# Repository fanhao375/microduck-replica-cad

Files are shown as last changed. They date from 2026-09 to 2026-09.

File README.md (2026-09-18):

# Microduck 复刻 · SolidWorks 三维图纸与装配说明书

> **可编辑的 SolidWorks 源文件**（不是 STL），外加一份 21 页的装配安装说明书。**两个版本**：
> **v2.0 飞特 HD-1910 版**（2026-09-12，已装出实物）和 **v1.1 原版 XL330 版**（2026-09-15，踝 / 小腿 / 脚同步改了）。
> 配套主仓：[**fanhao375/microduck-replica**](https://github.com/fanhao375/microduck-replica) —— 整机复刻、电路板与逆向分析都在那边。

> 📦 **压缩包在 [Releases 页](../../releases)（页面右边栏），不在上面的文件列表里。** 374 MB 的 SolidWorks 不适合塞进 git。
> 🖨️ **只想打印、不想看图** → [拓竹 MakerWorld · microduck 飞特版](https://makerworld.com.cn/zh/models/2963569-microduck#profileId-3478428)，一键切片（机械行者Robo 上传，就是这套飞特版）。

<div align="center">
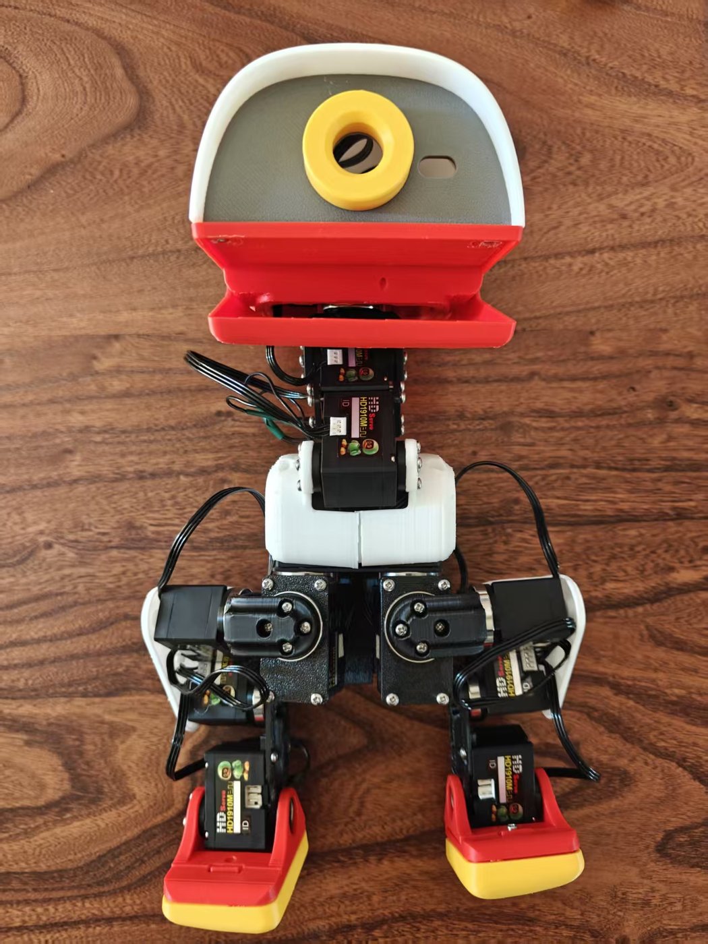
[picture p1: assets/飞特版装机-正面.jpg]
飞特 HD-1910 版装机实物
  
  <br><sub>2026-09-13 · 飞特 HD-1910 版装出来了，15 颗全在位</sub>
</div>

<div align="center">
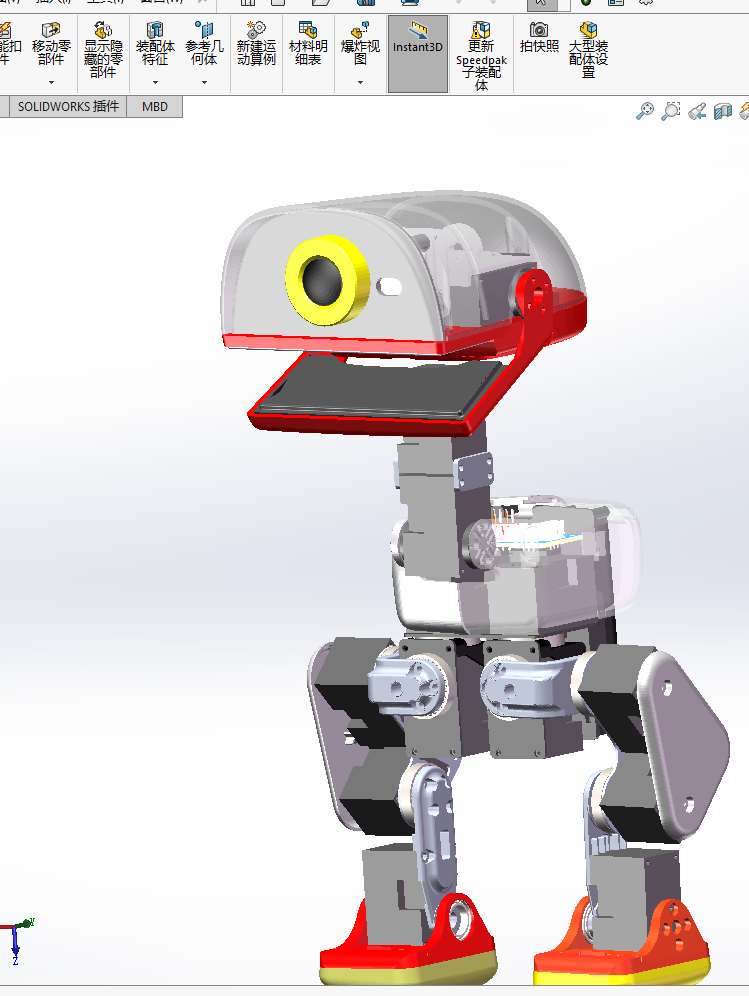
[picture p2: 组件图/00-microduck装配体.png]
microduck 装配体
  
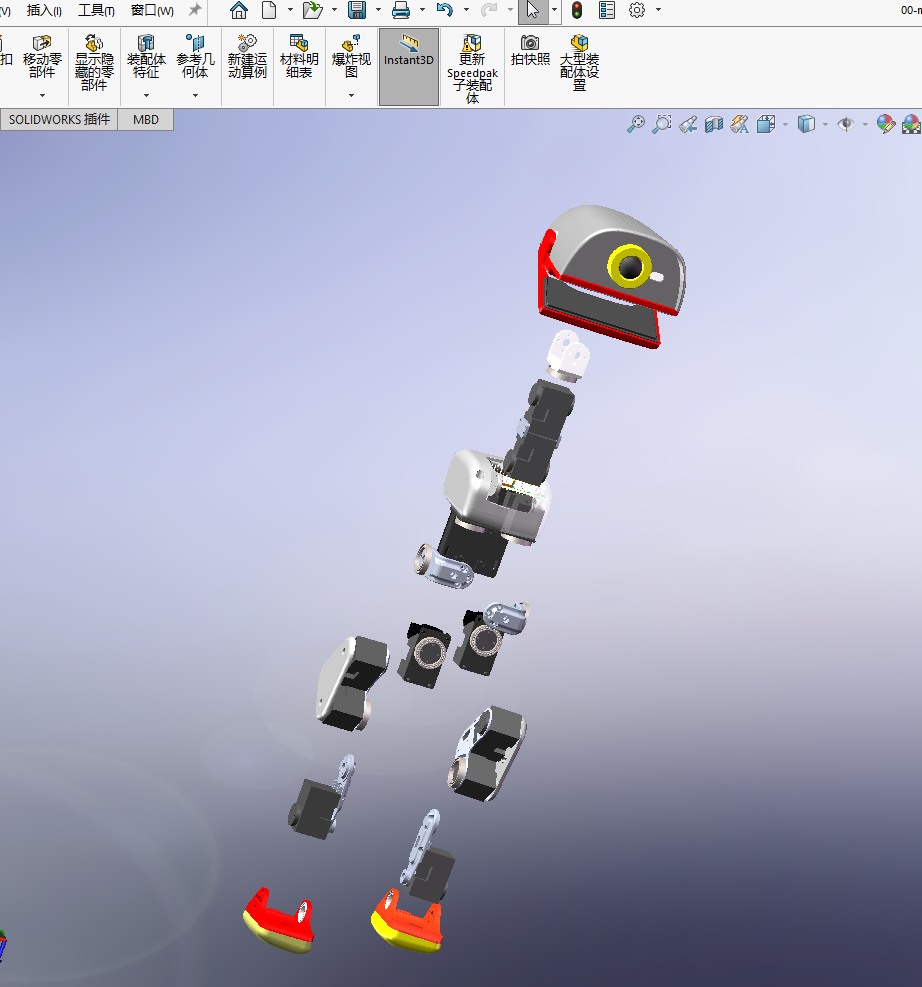
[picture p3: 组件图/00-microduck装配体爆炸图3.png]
microduck 爆炸图
  
</div>

---

## 两个版本，选一个下

| | 原版 · XL330 · **v1.1** | 飞特 · HD-1910 · **v2.0** |
|---|---|---|
| **舵机** | Dynamixel XL330-M288 | 飞特 HD-1910-C001 |
| **文件** | 57 个 SolidWorks，无后缀 | 62 个 SolidWorks + 9 个 STEP，`-FT` 后缀 |
| **差别** | — | **舵盘凸出**，8 个配合件改了（[改了什么](#飞特-hd-1910-版改了什么)） |
| **打印** | 主仓 [`print/`](https://github.com/fanhao375/microduck-replica/tree/master/print) 上游 STL | [`打印/` 3mf](打印/) · [拓竹一键打印](https://makerworld.com.cn/zh/models/2963569-microduck#profileId-3478428) |
| **实物** | — | 已装出（上图） |
| **下载** | [`SolidWorks-XL330-v1.1.zip`](https://github.com/fanhao375/microduck-replica-cad/releases/download/v1.1/SolidWorks-XL330-v1.1.zip) 333 MB | [`SolidWorks-FT.zip`](https://github.com/fanhao375/microduck-replica-cad/releases/download/v2.0/SolidWorks-FT.zip) 373 MB |

两版的踝 / 小腿 / 脚在 2026-09-15 同步成了一套设计；装配说明书和组件图两版通用。

---

## 图纸作者：机械行者Robo

**这套三维图纸和安装说明书，全部由「机械行者Robo」建模、整理、编写。**

他还在做装配视频，有装配上的问题去他那儿留言最快：

<table>
<tr>
<td align="center" width="50%">
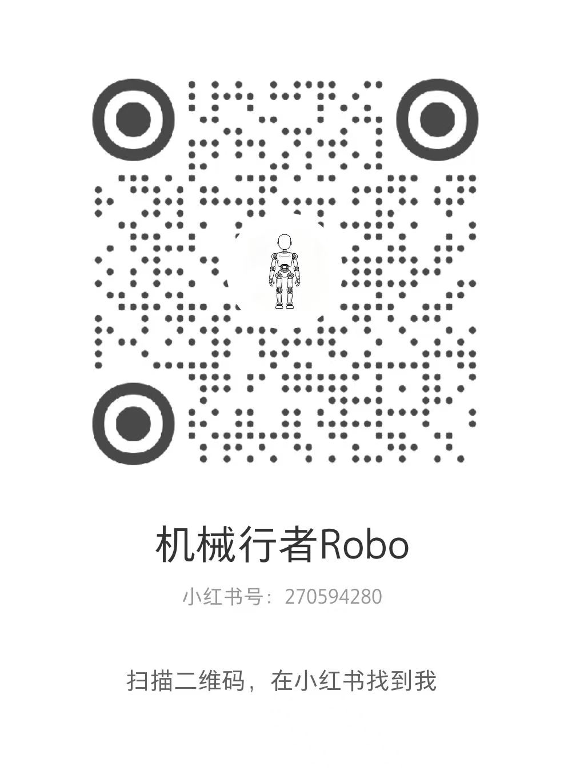
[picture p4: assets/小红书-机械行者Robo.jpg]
小红书 机械行者Robo
  <br>
  <b>小红书 · 机械行者Robo</b><br>
  <sub>小红书号 270594280</sub>
</td>
<td align="center" width="50%">
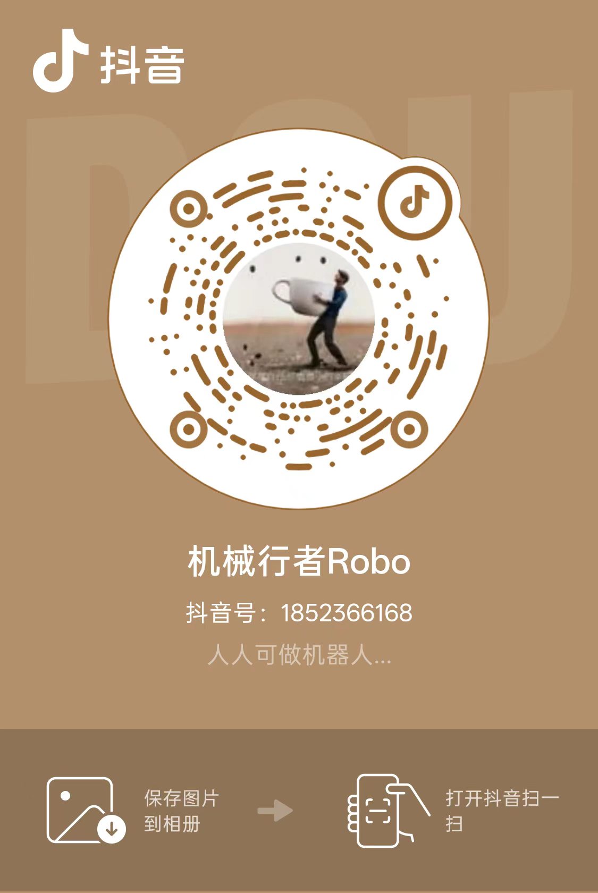
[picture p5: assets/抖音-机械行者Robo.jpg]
抖音 机械行者Robo
  <br>
  <b>抖音 · 机械行者Robo</b><br>
  <sub>抖音号 1852366168 —— 「人人可做机器人」</sub>
</td>
</tr>
</table>

> 觉得图纸有用的话，去关注一下他 —— 这套东西建模和整理的工作量不小，而且是免费放出来的。

---

## 下载

| 要什么 | 在哪 |
|---|---|
| **飞特 HD-1910 版源文件**（v2.0 · 62 个 SolidWorks + 9 个 STEP，解压 435 MB） | 👉 [**下载 `SolidWorks-FT.zip`**](https://github.com/fanhao375/microduck-replica-cad/releases/download/v2.0/SolidWorks-FT.zip) |
| **只要改动件的 STEP**（v2.0 · 9 个，15 MB） | 👉 [**下载 `STEP-changed-parts-FT.zip`**](https://github.com/fanhao375/microduck-replica-cad/releases/download/v2.0/STEP-changed-parts-FT.zip) —— 不用 SolidWorks 也能开 |
| **原版 XL330 版源文件**（v1.1 · 57 个 SolidWorks，解压 348 MB） | 👉 [**下载 `SolidWorks-XL330-v1.1.zip`**](https://github.com/fanhao375/microduck-replica-cad/releases/download/v1.1/SolidWorks-XL330-v1.1.zip)（[v1.0 旧版](../../releases/tag/v1.0) 仍可下） |
| **装配 BOM**（机械行者Robo 整理，35 个打印件 + 16 个外购件，含材料、数量，**2026-09-16 起带轴承和螺丝的采购链接**） | [`BOM/装配BOM-机械行者Robo-2026-09-16-带采购链接.xlsx`](BOM/装配BOM-机械行者Robo-2026-09-16-带采购链接.xlsx)，下面有校对过的表 |
| **装配安装说明书**（21 页 PDF） | [`安装说明书/microduck装配安装说明书.pdf`](安装说明书/microduck装配安装说明书.pdf) |
| **组件图 / 爆炸图**（23 张） | [`组件图/`](组件图/) |
| 🖨️ **打印工程文件**（Bambu Studio `.3mf`，4.9 MB，2026-09-15 版） | [`打印/microduck-飞特版-BambuStudio.3mf`](打印/microduck-飞特版-BambuStudio.3mf) —— **就在仓库里，直接下**。5 个盘、52 个件、P2S / PLA / 0.2 层高，跟拓竹上那个是同一份 |
| 🖨️ **拓竹一键打印** | [MakerWorld · microduck 飞特版](https://makerworld.com.cn/zh/models/2963569-microduck#profileId-3478428) —— 有拓竹打印机的直接云切片 |

> **为什么源文件放 Releases 不放 git**：SolidWorks 是二进制格式，git 存它既不能 diff 也不能合并，
> 只会一版版往历史里堆 —— 改三次图仓库就上 1 GB，而且**历史删不掉**。
> 放 Release 附件则不计入仓库体积，更新时发新版即可，clone 这个仓库始终只有几 MB。

---

## 飞特 HD-1910 版改了什么

原版用 Dynamixel XL330，本仓库主仓走飞特 HD-1910（更便宜、力矩大 2.5 倍、电压额定匹配 —— 见[主仓执行器选型](https://github.com/fanhao375/microduck-replica/blob/master/docs/执行器选型.md)）。
**两款舵机外形接近但舵盘不一样：HD-1910 的舵盘是凸出来的，XL330 是凹进去的。** 所有跟舵盘配合的件都得改：

| 改动件 | 为什么 |
|---|---|
| `left_upper_leg` / `right_upper_leg` 左右上腿 | 髋 pitch 和膝的舵盘位 |
| `leg` 小腿 | 膝和踝的舵盘位 |
| `trunk_base` 躯干底座 | 髋 yaw 舵机安装位 |
| `yaw2roll` 偏航转横滚 | 髋 yaw 舵盘 → 髋 roll 舵机 |
| `bearing_roll` 轴承滚轮 | 髋 roll 轴承座 |
| `01-upper_leg_rigidity_plate` 上腿加固板 | 跟上腿一起改 |
| `99-yaw_roll_motion` 偏航横滚运动 | 头部 yaw/roll，`-F` 和 `-FT` 两个变体 |

**文件命名**：所有件带 `-FT` 后缀（FT = 飞特）。没改的件也带 `-FT`，是为了整套装配体引用一致 —— 27 个件跟 v1.0 内容一样，只是改了名。

**多出来的**：`HD-1910-c001-dan / -shuang`（单盘 / 双盘舵机模型）、`舵机比较.SLDASM`（两款舵机并排对比）、`飞特电机资料1/`（飞特给的 STEP / DWG / 规格图）。

⚠️ 装配说明书 PDF 和组件图**还是 v1.0 的**，装配顺序和步骤不变，只是舵机换了。

---

## XL330 原版 v1.1 改了什么（2026-09-15）

飞特版改踝、小腿、脚那一片时顺手把原版也改了，两版这一区域现在是同一套设计：

```
改了   05_左小腿 · 06_左踝脚 · 14_右小腿 · 15_右踝脚 · 10_头部总成
       ankle_left 脚踝左 · foot_left 左脚 · leg 腿部
新增   deep groove ball bearings gb（轴承模型）
改名   00-microduck装配体 → 00-microduck装配体 XL330-288舵机版本
       ankle_right_脚踝右 → ankle_right脚踝右
```

46 个件跟 v1.0 一样。

---

## 装配 BOM

[`BOM/装配BOM-机械行者Robo-2026-09-16-带采购链接.xlsx`](BOM/装配BOM-机械行者Robo-2026-09-16-带采购链接.xlsx) 是机械行者Robo 按装配体整理的，2026-09-16 版给轴承和螺丝加了他实际下单的淘宝 / 天猫链接（小白照着买就行）。
表里电子件的型号和数量 2026-09-17 由 fanhao375 按主仓查证过的事实校过一遍（电池 NP-F550、舵机 15、`imu_to_dxl` 1、舵机线 17），下面这张表照它排。只有一处跟表不同：

| 表里 | 这里 | 依据 |
|---|---|---|
| 轮辋 / 轮胎 / 滚轮叶片 | 标为**轮滑变体，走路不用** | 上游 `变体-轮滑/`，只有做轮滑功能才打 |

### 一、3D 打印件（35 项）

| # | 零件 | 文件 | 材料 | 数量 | 备注 |
|---|---|---|---|---|---|
| 1 | 头部上壳 | `top_head_shell` | PLA | 1 | |
| 2 | 头部下壳 | `bottom_head_shell` | PLA | 1 | |
| 3 | 面部零件 | `face_part` | PLA | 1 | |
| 4 | 下巴 | `jaw` | PLA | 1 | |
| 5 | 软下巴 | `jaw_soft` | **TPU** | 1 | 软性件 |
| 6 | 软嘴顶部 | `soft_mouth_top` | **TPU** | 1 | 软性件 |
| 7 | 眼睛 | `noenoeil` | PLA | 1 | |
| 8 | 颈部 | `neck` | PLA | 2 | 可换铝合金增强 |
| 9 | 颈部俯仰 | `neck_pitch` | PLA | 1 | |
| 10 | 躯干底座 | `trunk_base` | PLA | 1 | 可换铝合金增强 |
| 11 | 左壳 | `left_shell` | PLA | 1 | |
| 12 | 右壳 | `right_shell` | PLA | 1 | |
| 13 | 髋部左 | `hip_l` | PLA | 2 | |
| 14 | 偏航转横滚 | `yaw2roll` | PLA | 1 | |
| 15 | 偏航横滚运动 | `yaw_roll_motion` | PLA | 1 | |
| 16 | 腿部 | `leg` | PLA | 2 | |
| 17 | 左上腿 | `left_upper_leg` | PLA | 1 | |
| 18 | 右上腿 | `right_upper_leg` | PLA | 1 | |
| 19 | 上腿加固板 | `upper_leg_rigidity_plate` | PLA | 2 | 可换铝合金增强 |
| 20 | 左脚 | `foot_left` | PLA | 1 | |
| 21 | 右脚 | `foot_right` | PLA | 1 | |
| 22 | 左脚底 | `sole_left` | PLA | 1 | |
| 23 | 右脚底 | `sole_right` | PLA | 1 | |
| 24 | 脚踝左 | `ankle_left` | PLA | 1 | |
| 25 | 脚踝右 | `ankle_right` | PLA | 1 | |
| 26 | 脚踝左 V1 | `ankle_l_v1` | PLA | 1 | 备选，与 24 二选一 |
| 27 | 脚踝右 V1 | `ankle_r_v1` | PLA | 1 | 备选，与 25 二选一 |
| 28 | 轮辋 | `rim` | PLA | 4 | **轮滑变体，走路不用** |
| 29 | 轮胎 | `tire` | TPU | 4 | **轮滑变体，走路不用** |
| 30 | 滚轮叶片 | `roller_blade` | PLA | 2 | **轮滑变体，走路不用** |
| 31 | M12 镜头座 | `m12_lens_holder` | PLA | 1 | |
| 32 | 电机支架 | `motor_support` | PLA | 1 | |
| 33 | 电源支架 | `power_support` | PLA | 1 | |
| 34 | 香蕉形 PCB 锁扣 | `banana_pcb_locker` | PLA | 1 | |
| 35 | 轴承滚轮 | `bearing_roll` | PLA | 2 | 可换铝合金增强 |

### 二、外购件（16 项 + 螺纹胶）

| # | 件 | 数量 | 备注 |
|---|---|---|---|
| 36 | Radxa Zero 3W 主控 | 1 | [主仓电控采购清单](https://github.com/fanhao375/microduck-replica/blob/master/docs/电控采购清单.md) |
| 37 | RPI Robot HAT 电路板 | 1 | 官方开源，嘉立创打样；或[不打 HAT 飞线](https://github.com/fanhao375/microduck-replica/blob/master/docs/不打HAT.md) |
| 38 | imu_to_dxl 电路板 | **1** | 主仓自绘，[hardware/imu_to_dxl](https://github.com/fanhao375/microduck-replica/tree/master/hardware/imu_to_dxl) |
| 39 | 舵机 | **15** | XL330-M288 或飞特 **HD-1910-C001** 二选一；13 单盘 + 2 双盘 |
| 40 | 舵机线缆 | 17 | 舵机自带一根，调试和总线分支要另买；飞特 2.0 mm、Dynamixel 2.5 mm |
| 41 | 电池 | 1 | **NP-F550**，2S |
| 42 | 电池座 | 1 | NP-F 电池仓 + 取电扣板 |
| 43 | IMX219 摄像头 | 1 | |
| 44 | 扬声器 | 1 | 走 HAT 音频才要 |
| 45 | 轴承 10×15×3 | 3 | 机械行者Robo 买的：[淘宝 963037239628](https://item.taobao.com/item.htm?id=963037239628&skuId=6069280211062)（选 10×15×3 那个 SKU） |
| 46 | 轴承 16×22×4 | 11 | 机械行者Robo 买的：[天猫 978199812185](https://detail.tmall.com/item.htm?id=978199812185&skuId=6245616343131) |
| 47 | 轴承 6×12×3 | 2 | 轮滑变体用，走路不用买。同一家：[淘宝 963037239628](https://item.taobao.com/item.htm?id=963037239628&skuId=6068333830994)（选 6×12×3） |
| 48 | 螺丝 M2×5 | 若干 | 机械行者Robo 买的：[天猫 637524754721](https://detail.tmall.com/item.htm?id=637524754721&skuId=5802482233046)；每种多少颗见[主仓紧固件反推](https://github.com/fanhao375/microduck-replica/blob/master/docs/紧固件反推.md) |
| 49 | 螺丝 M2×6 | 若干 | 同一家：[天猫 637524754721](https://detail.tmall.com/item.htm?id=637524754721&skuId=5802482233047) |
| 50 | 螺丝 M2.5×6 | 若干 | 同一家：[天猫 637524754721](https://detail.tmall.com/item.htm?id=637524754721&skuId=61808188996) |
| 51 | 螺纹胶 | 1 | 乐泰 243，原表没列，装配说明书要求 |

---

## 打印

**[`打印/microduck-飞特版-BambuStudio.3mf`](打印/microduck-飞特版-BambuStudio.3mf)** —— 机械行者Robo 排好盘的 Bambu Studio 工程，跟[拓竹 MakerWorld](https://makerworld.com.cn/zh/models/2963569-microduck#profileId-3478428) 上传的是同一份。

| 项 | 值 |
|---|---|
| 打印机 | Bambu Lab **P2S**，0.4 喷嘴 |
| 耗材 | PLA Basic |
| 层高 | 0.2 mm |
| 盘数 | **5 盘**，52 个对象 —— 飞特版全部打印件 |

<table>
<tr>
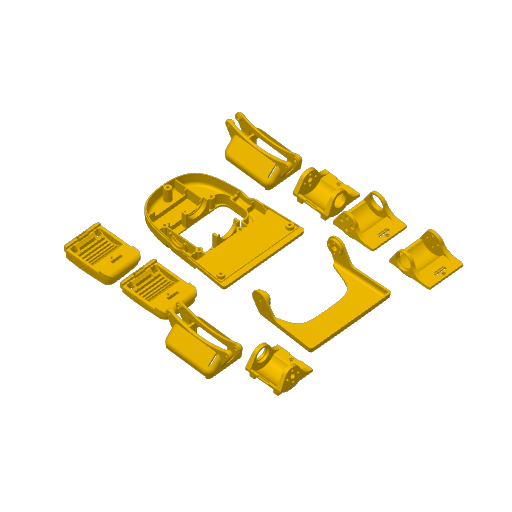
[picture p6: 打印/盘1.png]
<td align="center"><br><sub>盘 1</sub></td>
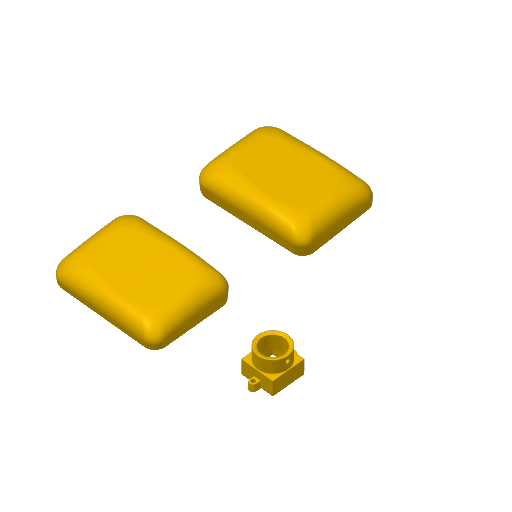
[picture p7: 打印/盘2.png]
<td align="center"><br><sub>盘 2</sub></td>
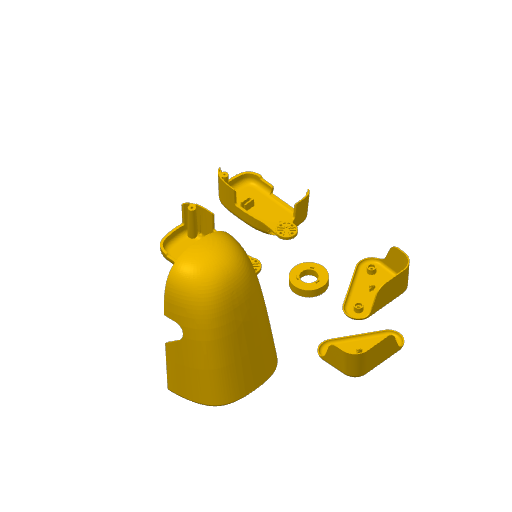
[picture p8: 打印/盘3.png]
<td align="center"><br><sub>盘 3</sub></td>
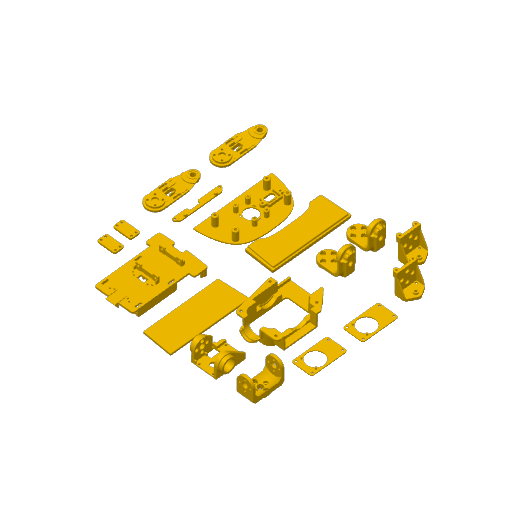
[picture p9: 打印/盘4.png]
<td align="center"><br><sub>盘 4</sub></td>
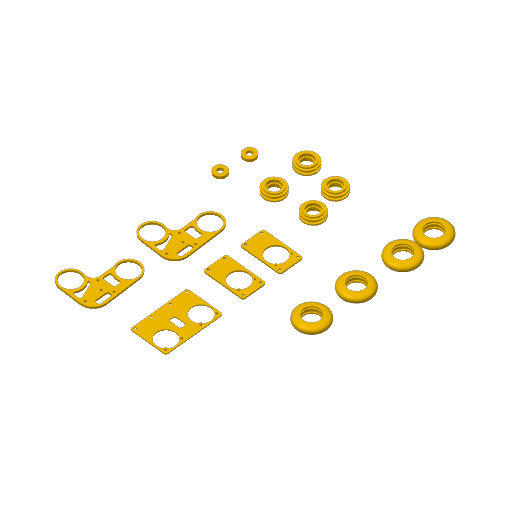
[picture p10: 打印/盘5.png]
<td align="center"><br><sub>盘 5</sub></td>
</tr>
</table>

**怎么用**：Bambu Studio 打开 → 切片 → 打印，五盘依次来。**不是拓竹打印机**也能用：任何切片软件都能导入 `.3mf` 拿到模型和排盘，只是打印参数要按自己的机器重设。

耗材、螺丝、热熔螺母的采购在[主仓机械采购清单](https://github.com/fanhao375/microduck-replica/blob/master/docs/机械采购清单.md)。

---

## 组件清单（15 个）

| 序号 | 组件 | 英文 | 位置 / 功能 |
|---|---|---|---|
| 01 | 躯干主体 | Torso | 机身主体，**全部组件的装配基准件**，承载左/右腿、颈部与控制器 |
| 02 | 左髋 | Left Hip | 左腿根部髋关节（Pitch），腿部前后摆动 |
| 03 | 左髋 Roll | Left Hip Roll | 左腿髋部横滚关节，腿部侧向摆动 |
| 04 | 左大腿 | Left Thigh | 连接髋关节与小腿 |
| 05 | 左小腿 | Left Calf | 连接大腿与踝关节 |
| 06 | 左踝脚 | Left Ankle & Foot | 踝关节及脚部，足部转动与支撑 |
| 07 | 颈根 | Neck Base | 颈部与机身连接处的旋转底座（Yaw） |
| 08 | 颈俯仰 | Neck Pitch | 颈部俯仰摆动关节 |
| 09 | 头 Yaw / Roll | Head Yaw / Roll | 头部水平摆动与横滚关节 |
| 10 | 头部总成 | Head Assembly | 头部完整组件，含外壳、摄像头等 |
| 11 | 右髋 | Right Hip | 与 02 镜像对称 |
| 12 | 右髋 Roll | Right Hip Roll | 与 03 镜像对称 |
| 13 | 右大腿 | Right Thigh | 与 04 镜像对称 |
| 14 | 右小腿 | Right Calf | 与 05 镜像对称 |
| 15 | 右踝脚 | Right Ankle & Foot | 与 06 镜像对称 |

## 装配顺序

**按编号 01 → 15 依次装，就是推荐的整机装配顺序：**

```
1.  01           躯干主体 —— 作为整机基准先行固定
2.  02 → 06      左腿   左髋 → 左髋Roll → 左大腿 → 左小腿 → 左踝脚
3.  07 → 10      颈头   颈根 → 颈俯仰 → 头Yaw/Roll → 头部总成
4.  11 → 15      右腿   右髋 → 右髋Roll → 右大腿 → 右小腿 → 右踝脚
```

**每一步的详细步骤、配图和注意事项，见** [装配安装说明书 PDF](安装说明书/microduck装配安装说明书.pdf)。

---

## 组件图

<table>
<tr>
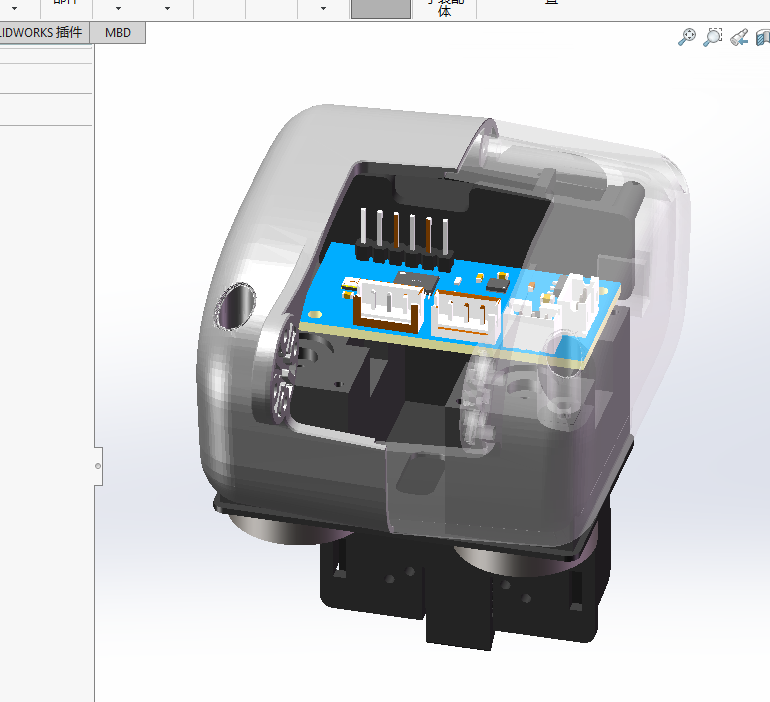
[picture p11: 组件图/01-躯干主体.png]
<td align="center"><br><sub><b>01</b> 躯干主体</sub></td>
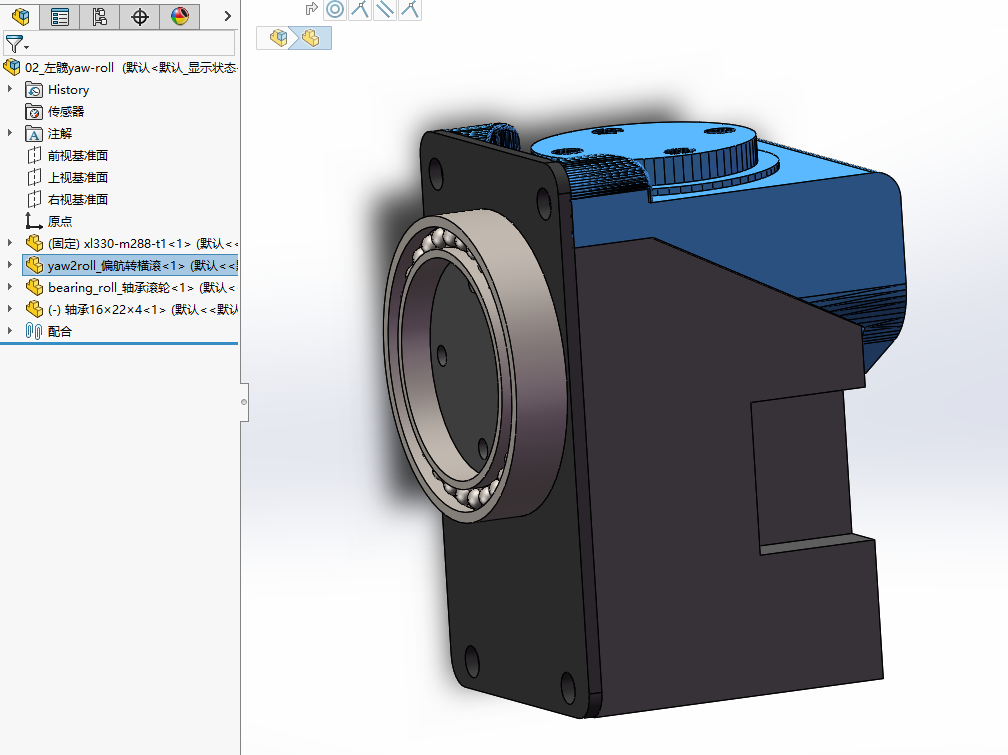
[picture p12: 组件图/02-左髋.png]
<td align="center"><br><sub><b>02</b> 左髋</sub></td>
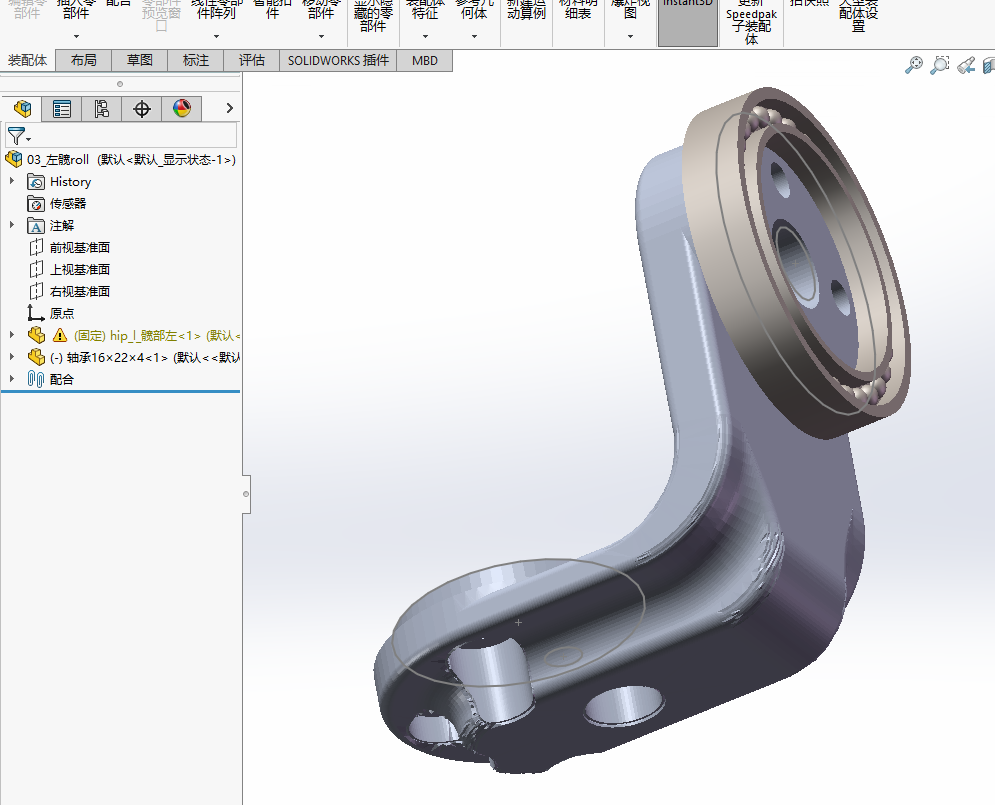
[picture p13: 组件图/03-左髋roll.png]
<td align="center"><br><sub><b>03</b> 左髋 Roll</sub></td>
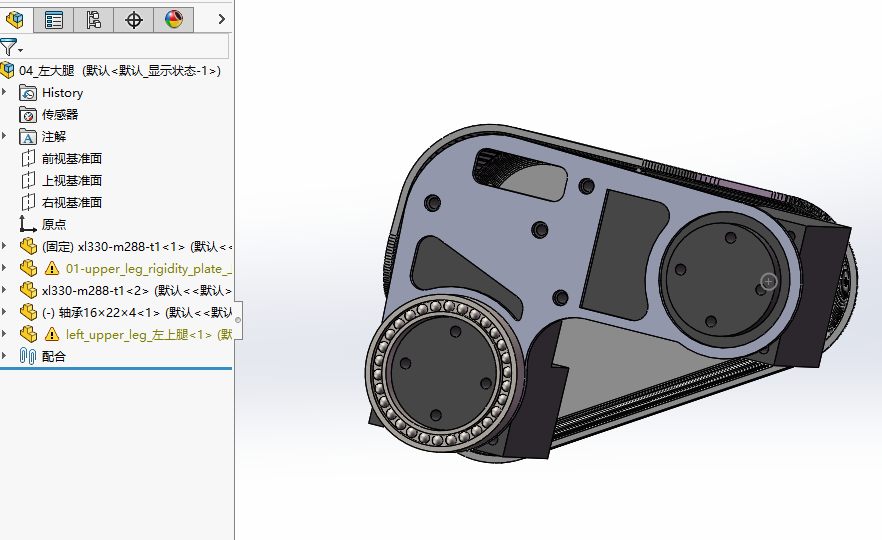
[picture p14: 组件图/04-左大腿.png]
<td align="center"><br><sub><b>04</b> 左大腿</sub></td>
</tr>
<tr>
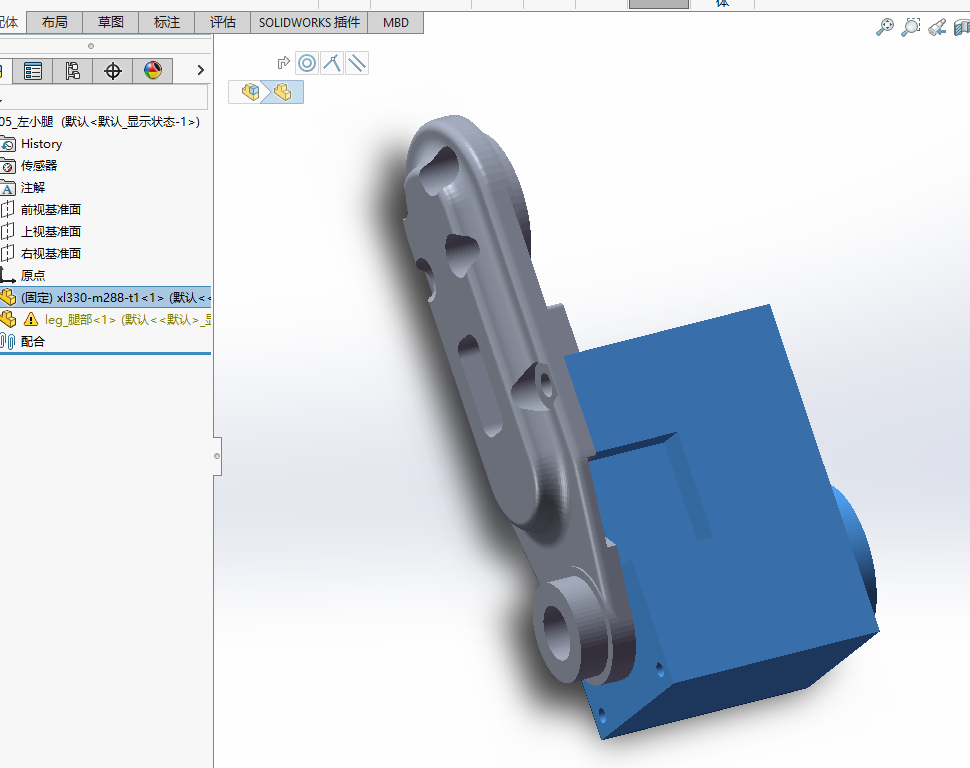
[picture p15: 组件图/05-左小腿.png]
<td align="center"><br><sub><b>05</b> 左小腿</sub></td>
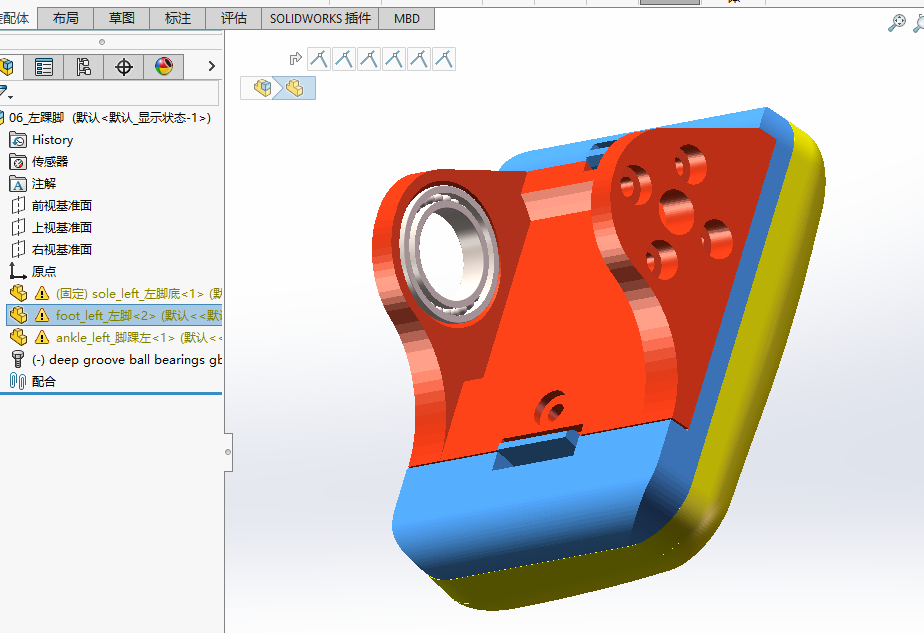
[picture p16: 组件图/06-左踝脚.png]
<td align="center"><br><sub><b>06</b> 左踝脚</sub></td>
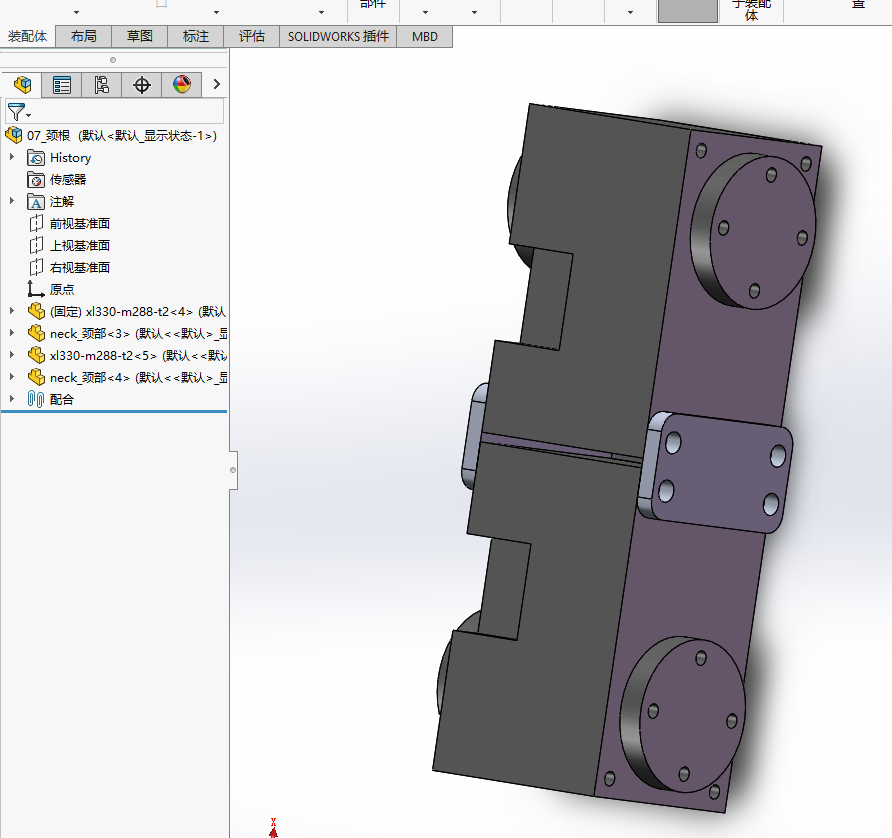
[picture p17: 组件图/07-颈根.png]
<td align="center"><br><sub><b>07</b> 颈根</sub></td>
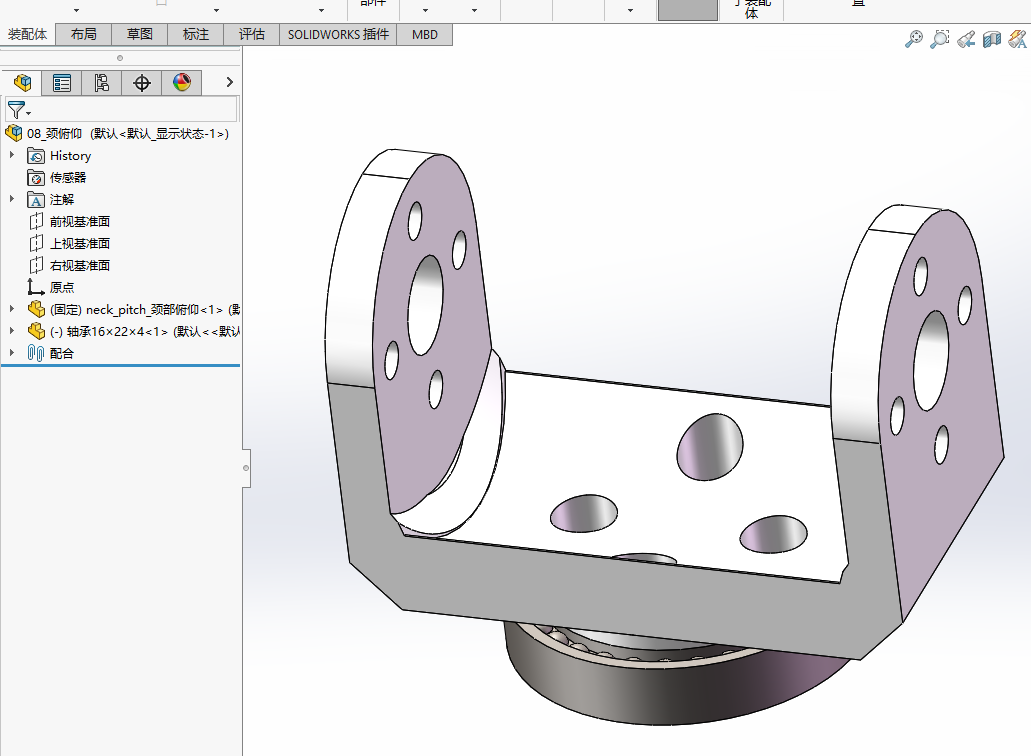
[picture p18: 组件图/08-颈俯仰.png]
<td align="center"><br><sub><b>08</b> 颈俯仰</sub></td>
</tr>
<tr>
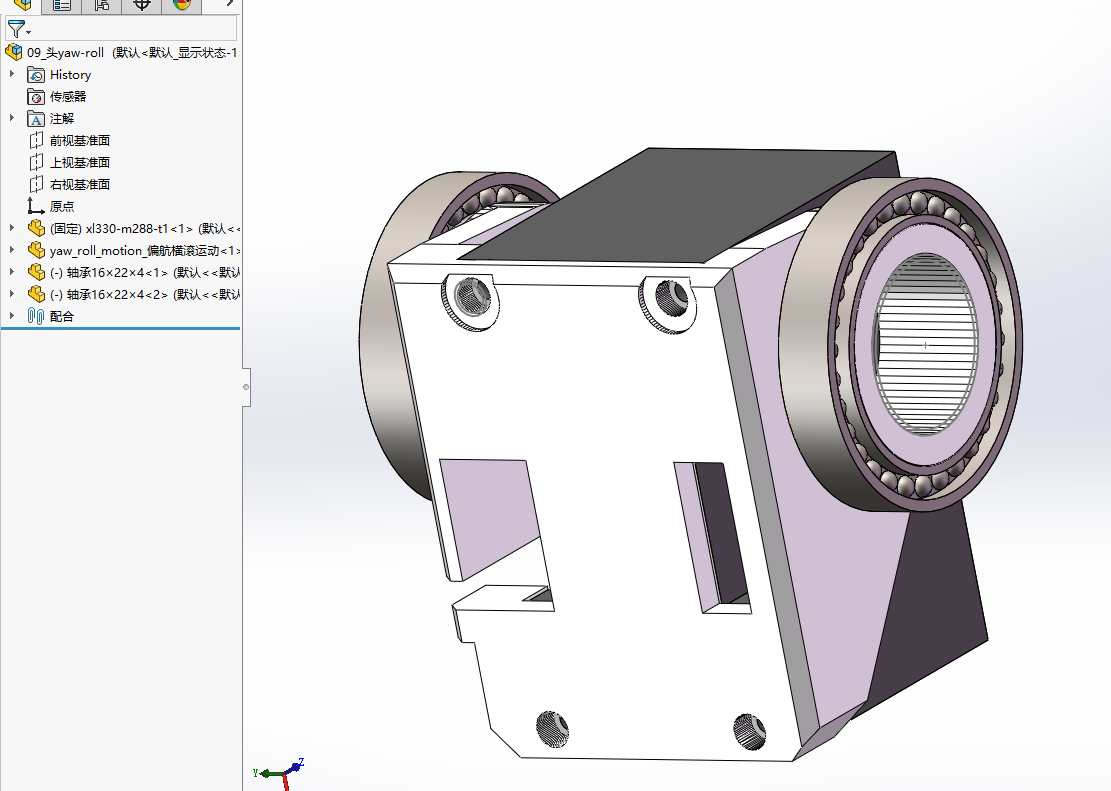
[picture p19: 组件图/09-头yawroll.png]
<td align="center"><br><sub><b>09</b> 头 Yaw/Roll</sub></td>
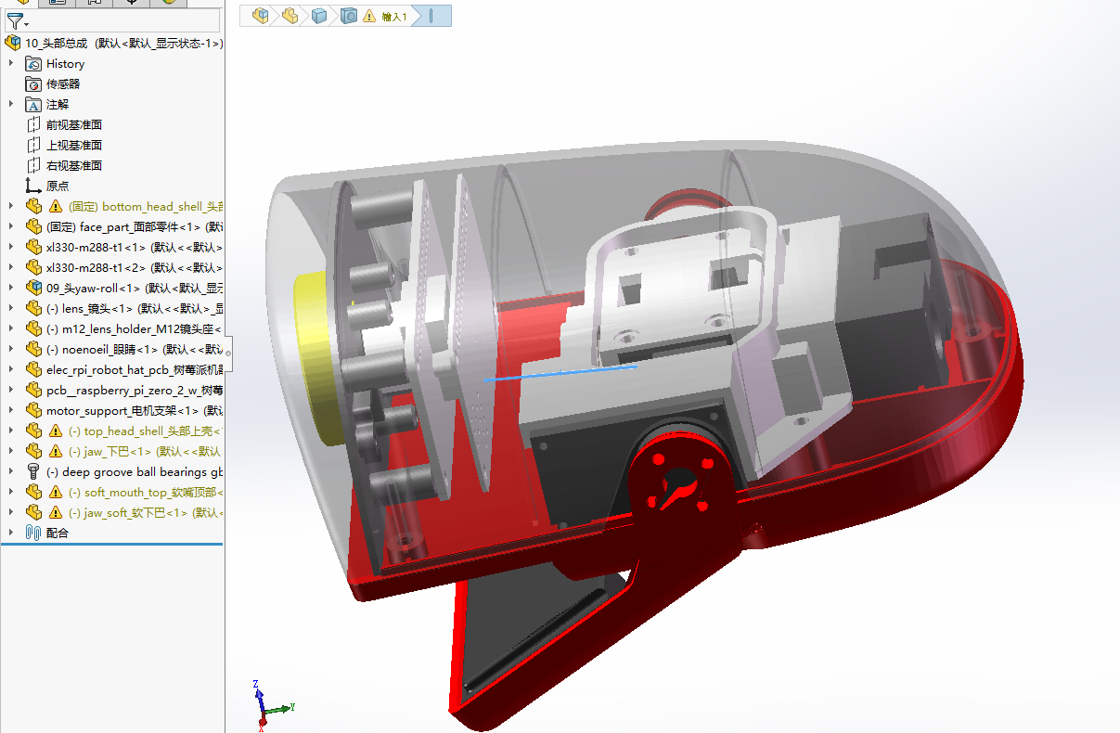
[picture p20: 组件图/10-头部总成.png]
<td align="center"><br><sub><b>10</b> 头部总成</sub></td>
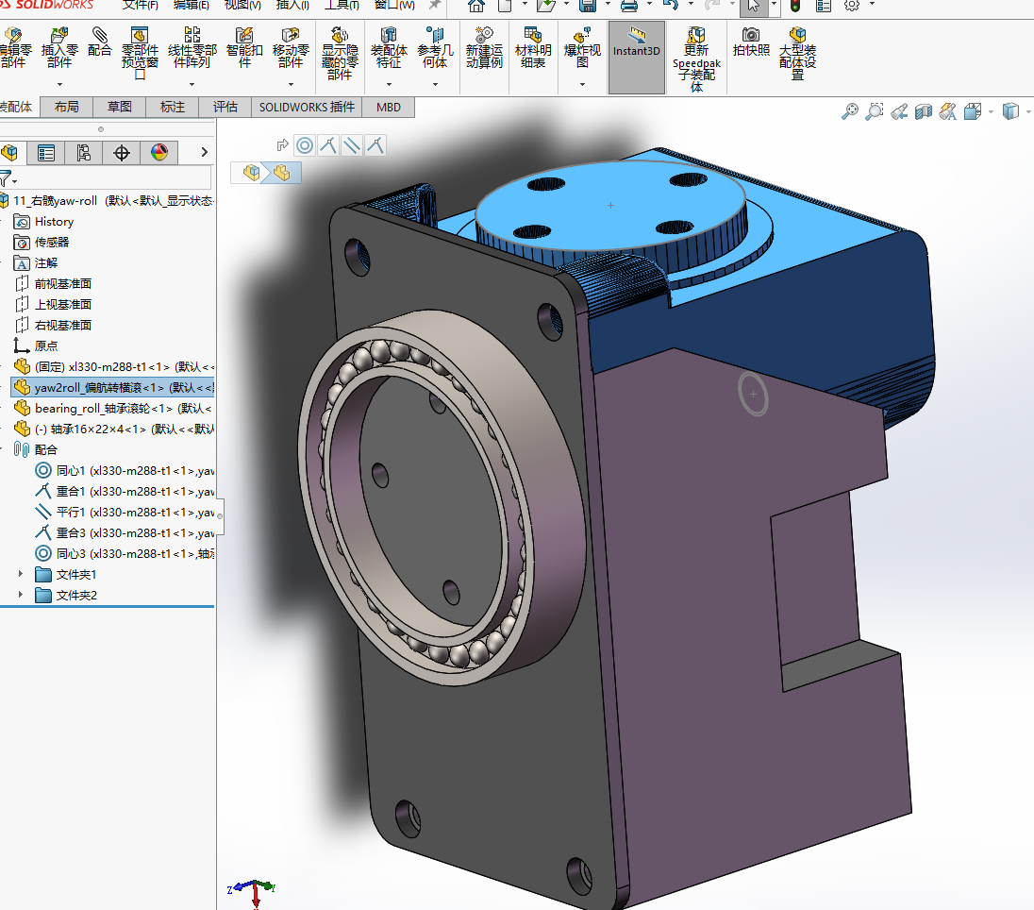
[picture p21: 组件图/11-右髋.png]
<td align="center"><br><sub><b>11</b> 右髋</sub></td>
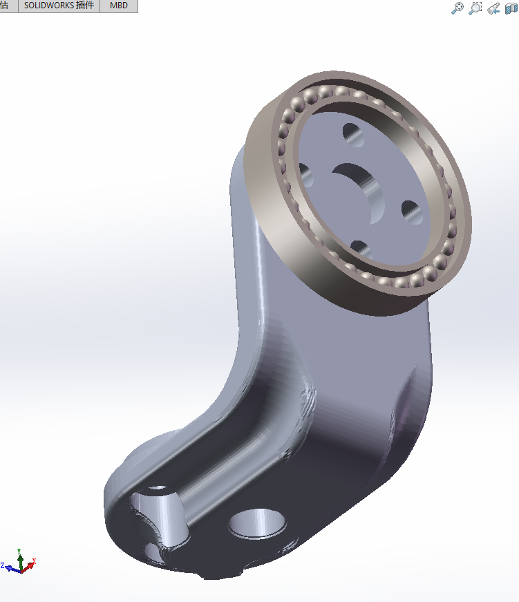
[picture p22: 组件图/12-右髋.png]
<td align="center"><br><sub><b>12</b> 右髋 Roll</sub></td>
</tr>
<tr>
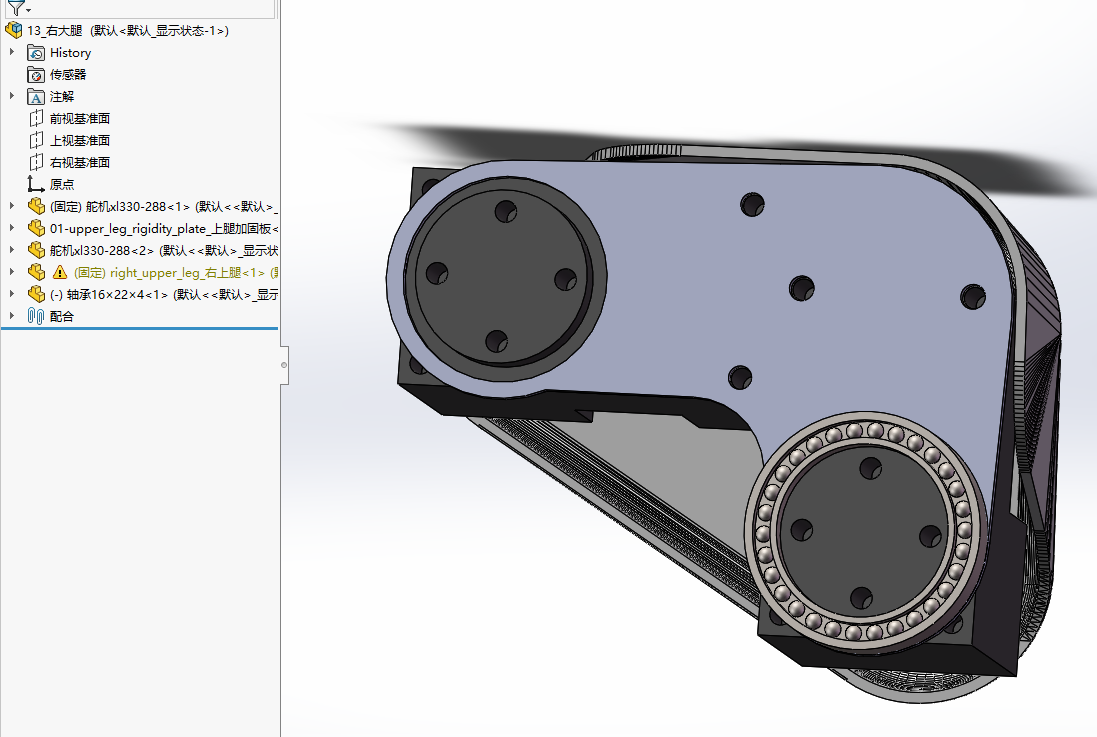
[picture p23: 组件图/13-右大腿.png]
<td align="center"><br><sub><b>13</b> 右大腿</sub></td>
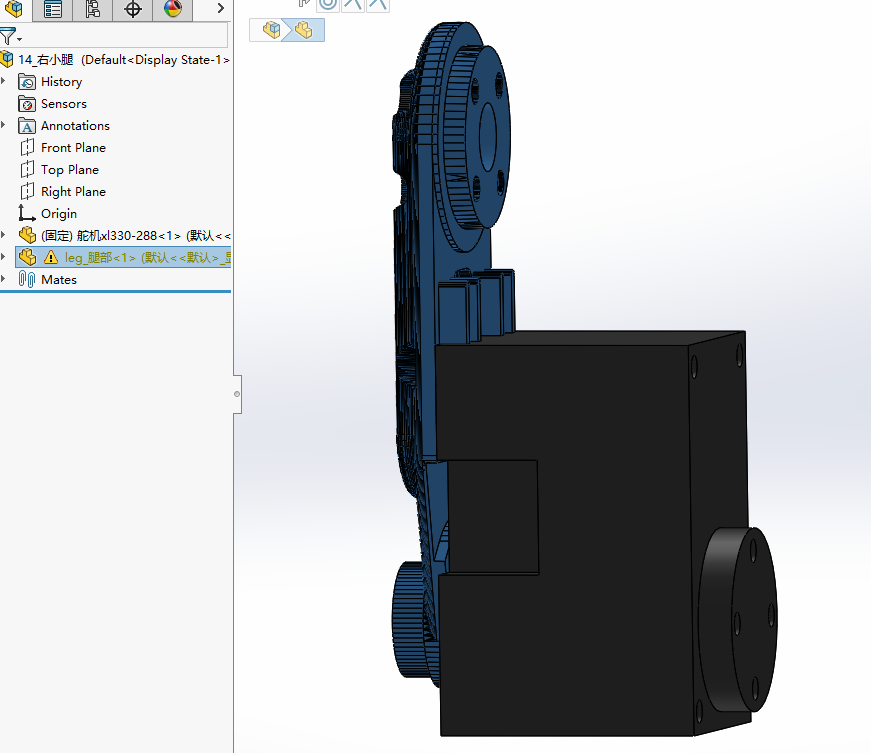
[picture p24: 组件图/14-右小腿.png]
<td align="center"><br><sub><b>14</b> 右小腿</sub></td>
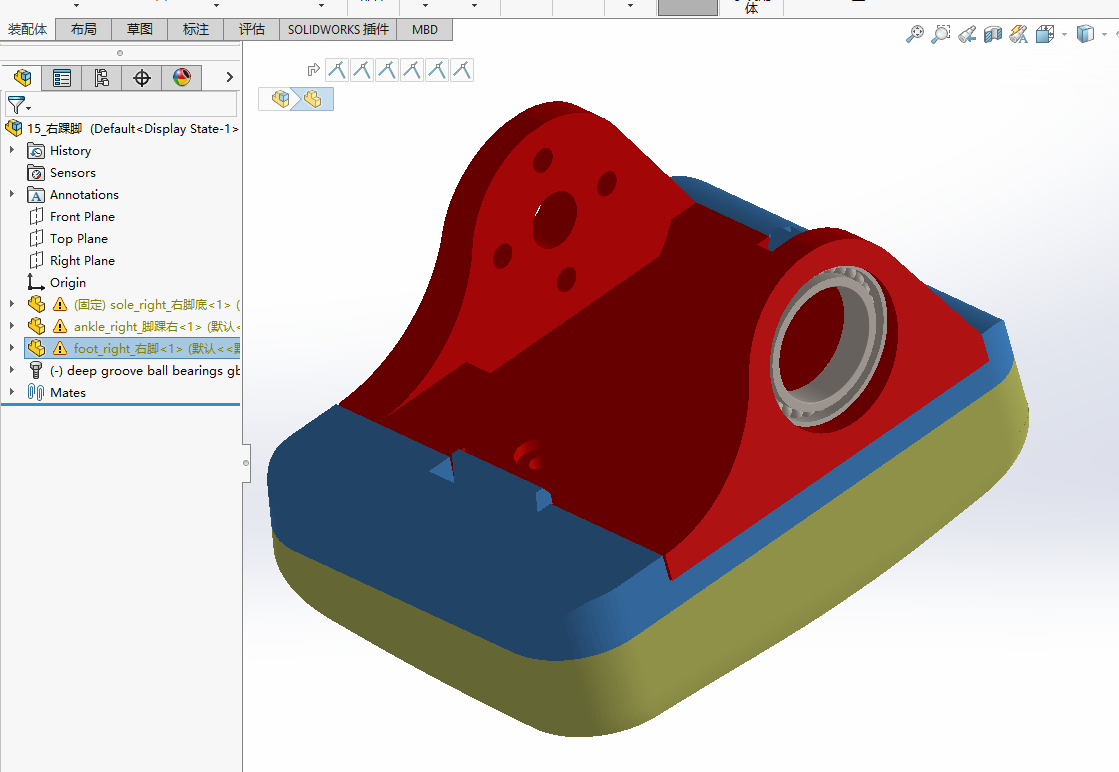
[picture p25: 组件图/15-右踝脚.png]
<td align="center"><br><sub><b>15</b> 右踝脚</sub></td>
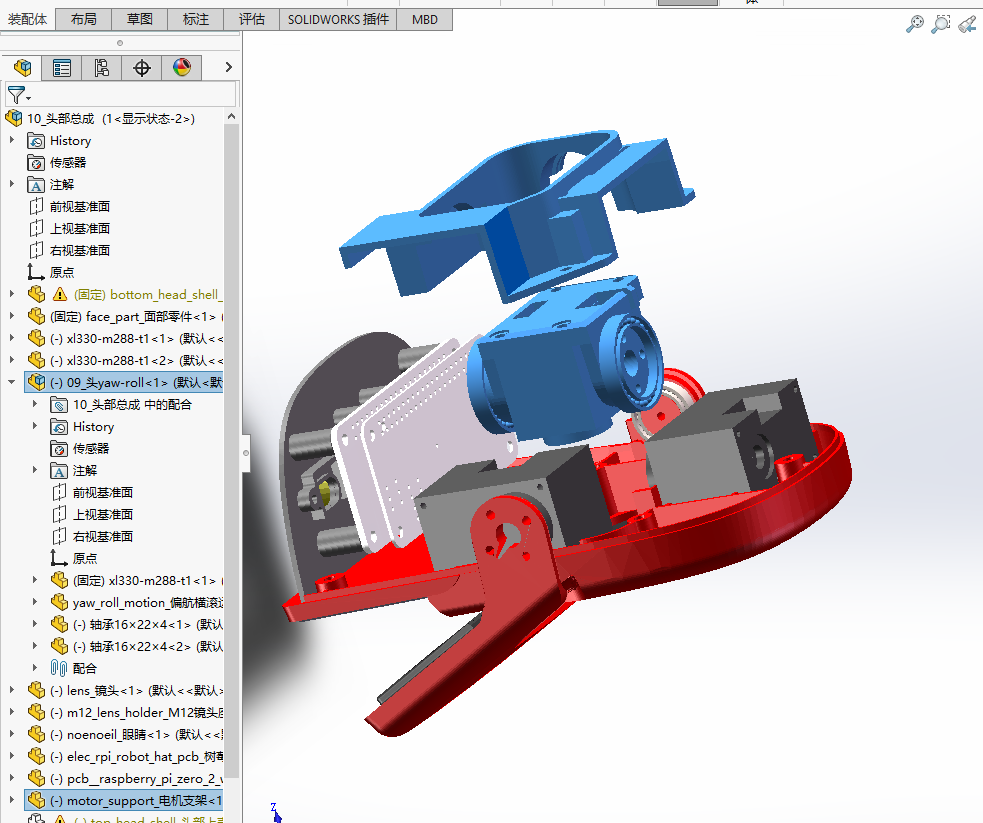
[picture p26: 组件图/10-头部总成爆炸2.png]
<td align="center"><br><sub>头部总成（爆炸）</sub></td>
</tr>
</table>

<div align="center">
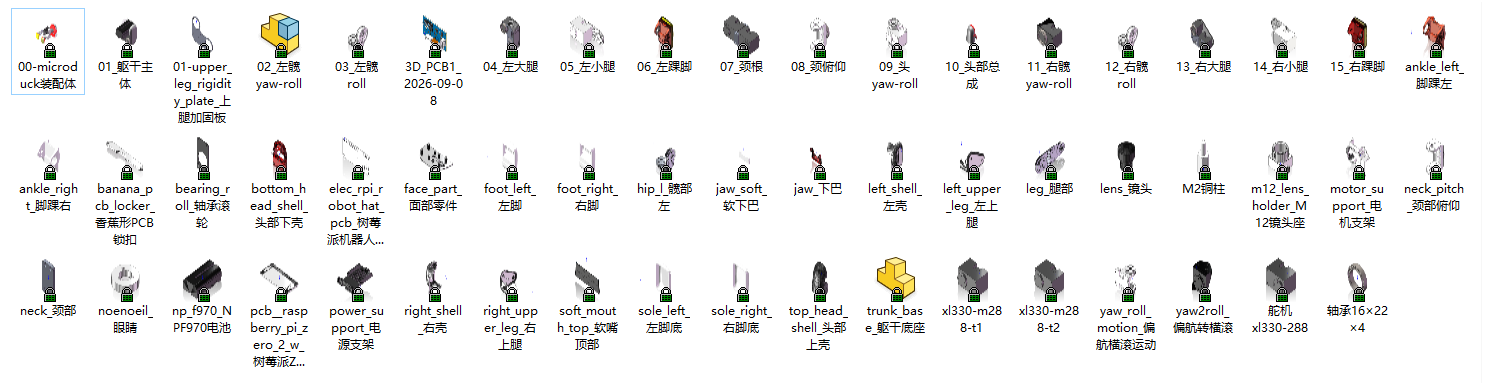
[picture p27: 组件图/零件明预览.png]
零件总览
  <br>
  <sub>全部零件总览</sub>
</div>

---

## 文件清单

### 装配体（16 个 `.SLDASM`）

`00-microduck装配体` 是总装，下面 15 个是分组件：

```
00-microduck装配体      70.3 MB      08_颈俯仰               0.3 MB
01_躯干主体             20.5 MB      09_头yaw-roll          0.7 MB
02_左髋yaw-roll         2.5 MB      10_头部总成             22.2 MB
03_左髋roll             3.8 MB      11_右髋yaw-roll         2.5 MB
04_左大腿               1.9 MB      12_右髋roll             3.8 MB
05_左小腿               1.9 MB      13_右大腿               2.0 MB
06_左踝脚               9.3 MB      14_右小腿               1.8 MB
07_颈根                 0.1 MB      15_右踝脚               9.3 MB
```

### 零件（40 个 `.SLDPRT`）

| 类别 | 零件 |
|---|---|
| **躯干 / 外壳** | `trunk_base_躯干底座` · `left_shell_左壳` · `right_shell_右壳` · `power_support_电源支架` · `banana_pcb_locker_香蕉形PCB锁扣` |
| **腿** | `leg_腿部` · `left_upper_leg_左上腿` · `right_upper_leg_右上腿` · `hip_l_髋部左` · `yaw2roll_偏航转横滚` · `yaw_roll_motion_偏航横滚运动` · `01-upper_leg_rigidity_plate_上腿加固板` |
| **踝 / 脚** | `ankle_left_脚踝左` · `ankle_right_脚踝右` · `foot_left_左脚` · `foot_right_右脚` · `sole_left_左脚底` · `sole_right_右脚底` |
| **颈 / 头** | `neck_颈部` · `neck_pitch_颈部俯仰` · `top_head_shell_头部上壳` · `bottom_head_shell_头部下壳` · `face_part_面部零件` · `jaw_下巴` · `jaw_soft_软下巴` · `soft_mouth_top_软嘴顶部` · `noenoeil_眼睛` |
| **摄像头** | `m12_lens_holder_M12镜头座` · `lens_镜头` |
| **电路板** | `3D_PCB1_2026-09-08`（imu_to_dxl，2026-09-08 版）· `elec_rpi_robot_hat_pcb_树莓派机器人HAT电路板` · `pcb__raspberry_pi_zero_2_w_树莓派Zero2W电路板` |
| **标准件 / 外购** | `舵机xl330-288` · `xl330-m288-t1` · `xl330-m288-t2` · `轴承16×22×4` · `bearing_roll_轴承滚轮` · `M2铜柱` · `motor_support_电机支架` · `np_f970_NPF970电池` |

### 两处命名要留意

- **`np_f970_NPF970电池`** —— 文件名沿用了上游的 `np_f970`，但**实物是 NP-F550**。
  主仓实测上游网格包围盒为 **70.8 × 38.6 × 20.6 mm**，正是 F550/F570 的尺寸；真 NP-F970 厚约 60 mm，
  **买错装不进去，而且 300 g 会吃掉整机预算的三分之一**。详见
  [主仓 BOM 的电池型号勘误](https://github.com/fanhao375/microduck-replica/blob/master/BOM.md)。
- **`pcb__raspberry_pi_zero_2_w`** —— 同样是上游的占位命名，**实机主控是 Radxa Zero 3W**（RK3566），
  只是外形同为 Pi Zero。见[主仓的硬件方案逆向](https://github.com/fanhao375/microduck-replica/blob/master/docs/硬件方案逆向.md)。

---

## 通用注意事项（摘自说明书）

- 装配前对照 BOM 清点零件数量与规格，确认 **M2 / M2.5** 螺丝与紧固件齐全
- **舵机类关节件：装配前先通电归中位再锁紧**，避免行程偏移
- 螺丝**对角分步预紧**，避免单边受力导致零件变形；塑料件切勿过度锁紧
- **左右对称件（髋 / 大腿 / 小腿 / 踝脚）务必区分左右**，切勿装反
- 线缆统一固定、预留关节活动余量，严禁压线、夹线、缠绕
- 每完成一个活动关节，转动测试一次，检查是否干涉、卡滞、异响
- 首次通电前检查所有电气连接、绝缘与极性

**推荐工具**：十字/内六角螺丝刀 · 镊子 · 螺纹胶 · 舵机中位调试工具或控制板。

---

## 声明与许可

> ⚠️ **这是第三方复刻件，不是官方设计。** 与 Pollen Robotics 无隶属关系，未获其背书。

本套图纸依据 [`pollen-robotics/microduck_rl`](https://github.com/pollen-robotics/microduck_rl) 公开发布的
STL 网格重建为可编辑的 SolidWorks 参数模型。上游 3D 模型许可为 **CC BY-NC-SA**，
因此本仓库的图纸作为衍生作品同样以 **[CC BY-NC-SA 4.0](https://creativecommons.org/licenses/by-nc-sa/4.0/deed.zh)** 发布：
**署名 · 非商业性使用 · 相同方式共享**。

- **图纸与说明书著作权归「机械行者Robo」**，转载与二次分发请保留署名
- 文档文字部分同样按 CC BY-NC-SA 4.0 发布
- Microduck 是 Pollen Robotics 的商业产品，本仓库不提供任何官方支持

**发现问题**请开 [issue](../../issues)，或到上面两个账号留言。

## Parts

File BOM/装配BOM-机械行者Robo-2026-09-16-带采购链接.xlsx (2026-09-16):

序号 | 类别 | 名称 | 原文件名 | 材料 | 数量 | 备注
一、3D打印件（需打印）
1 | 3D打印件 | 头部上壳 | top_head_shell_头部上壳.stp | PLA | 1
2 | 3D打印件 | 头部下壳 | bottom_head_shell_头部下壳.stp | PLA | 1
3 | 3D打印件 | 面部零件 | face_part_面部零件.stp | PLA | 1
4 | 3D打印件 | 下巴 | jaw_下巴.stp | PLA | 1
5 | 3D打印件 | 软下巴 | jaw_soft_软下巴.stp | PLA | 1 | 软性件，建议改用TPU软料
6 | 3D打印件 | 软嘴顶部 | soft_mouth_top_软嘴顶部.stp | PLA | 1 | 软性件，建议改用TPU软料
7 | 3D打印件 | 眼睛 | noenoeil_眼睛.stp | PLA | 1
8 | 3D打印件 | 颈部 | neck_颈部.stp | PLA | 2 | 可用铝合金，增加强度
9 | 3D打印件 | 颈部俯仰 | neck_pitch_颈部俯仰.stp | PLA | 1
10 | 3D打印件 | 躯干底座 | trunk_base_躯干底座.stp | PLA | 1 | 可用铝合金，增加强度
11 | 3D打印件 | 左壳 | left_shell_左壳.stp | PLA | 1
12 | 3D打印件 | 右壳 | right_shell_右壳.stp | PLA | 1
13 | 3D打印件 | 髋部左 | hip_l_髋部左.stp | PLA | 2
14 | 3D打印件 | 偏航转横滚 | yaw2roll_偏航转横滚.stp | PLA | 1
15 | 3D打印件 | 偏航横滚运动 | yaw_roll_motion_偏航横滚运动.stp | PLA | 1
16 | 3D打印件 | 腿部 | leg_腿部.stp | PLA | 2
17 | 3D打印件 | 左上腿 | left_upper_leg_左上腿.stp | PLA | 1
18 | 3D打印件 | 右上腿 | right_upper_leg_右上腿.stp | PLA | 1
19 | 3D打印件 | 上腿加固板 | upper_leg_rigidity_plate_上腿加固板.stp | PLA | 2 | 可用铝合金，增加强度
20 | 3D打印件 | 左脚 | foot_left_左脚.stp | PLA | 1
21 | 3D打印件 | 右脚 | foot_right_右脚.stp | PLA | 1
22 | 3D打印件 | 左脚底 | sole_left_左脚底.stp | PLA | 1
23 | 3D打印件 | 右脚底 | sole_right_右脚底.stp | PLA | 1
24 | 3D打印件 | 脚踝左 | ankle_left_脚踝左.stp | PLA | 1
25 | 3D打印件 | 脚踝右 | ankle_right_脚踝右.stp | PLA | 1
26 | 3D打印件 | 脚踝左(V1备选) | ankle_l_v1_脚踝左V1.stp | PLA | 1 | V1备选版，与脚踝左二选一
27 | 3D打印件 | 脚踝右(V1备选) | ankle_r_v1_脚踝右V1.stp | PLA | 1 | V1备选版，与脚踝右二选一
28 | 3D打印件 | 轮辋(轮毂) | rim_轮辋.stp | PLA | 4
29 | 3D打印件 | 轮胎 | tire_轮胎.stp | TPU | 4 | 软性件，建议TPU软料
30 | 3D打印件 | 滚轮叶片 | roller_blade_滚轮叶片.stp | PLA | 2
31 | 3D打印件 | M12镜头座 | m12_lens_holder_M12镜头座.stp | PLA | 1
32 | 3D打印件 | 电机支架 | motor_support_电机支架.stp | PLA | 1
33 | 3D打印件 | 电源支架 | power_support_电源支架.stp | PLA | 1
34 | 3D打印件 | 香蕉形PCB锁扣 | banana_pcb_locker_香蕉形PCB锁扣.stp | PLA | 1
35 | 3D打印件 | 轴承滚轮 | bearing_roll_轴承滚轮.stp | PLA | 2 | 可用铝合金，增加强度
二、外购标准件（无需打印） |  |  |  |  |  | 网址
35 | 外购件 | Radxa Zero 3W 主控板 |  | 电子件 | 1
36 | 外购件 | 树莓派机器人HAT电路板 | 嘉立创 | 电子件 | 1
37 | 外购件 | imu_to_dxl电路板 | 嘉立创 | 电子件 | 1
38 | 外购件 | XL330-M288舵机 |  | 电子件 | 15
39 | 外购件 | 飞特HD1901M舵机 | 和上述舵机二选一 13个单盘，2个双盘 | 电子件 | 15
40 | 外购件 | HD1901M舵机舵机线缆 | 舵机带线路，但调试需要，需额外采购 | 电子件 | 17
41 | 外购件 | NP-F550电池 |  | 电子件 | 1
42 | 外购件 | 电池座 |  | 电子件 | 1
43 | 外购件 | IMX219摄像头模块 |  | 光学件 | 1
44 | 外购件 | 扬声器 |  | 电子件 | 1
45 | 外购件 | 轴承 10×15×3 |  | 标准件 | 3 | https://item.taobao.com/item.htm?id=963037239628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
46 | 外购件 | 轴承 16×22×4 |  | 标准件 | 11 | https://detail.tmall.com/item.htm?id=978199812185&skuId=6245616343131
47 | 外购件 | 轴承 6×12×3 | 轮滑鞋用轴承 | 标准件 | 2 | https://item.taobao.com/item.htm?id=963037239628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
48 | 外购件 | 螺丝M2×5 |  | 标准件 | 若干 | https://detail.tmall.com/item.htm?ali_trackid=318_52a09f69533ca8994dc6d0b507aea17b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
49 | 外购件 | 螺丝M2×6 |  | 标准件 | 若干 | https://detail.tmall.com/item.htm?ali_trackid=318_52a09f69533ca8994dc6d0b507aea17b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
50 | 外购件 | 螺丝M2.5×6 |  | 标准件 | 若干 | https://detail.tmall.com/item.htm?ali_trackid=318_52a09f69533ca8994dc6d0b507aea17b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
合计：3D打印件 35 项 / 外购件 16项

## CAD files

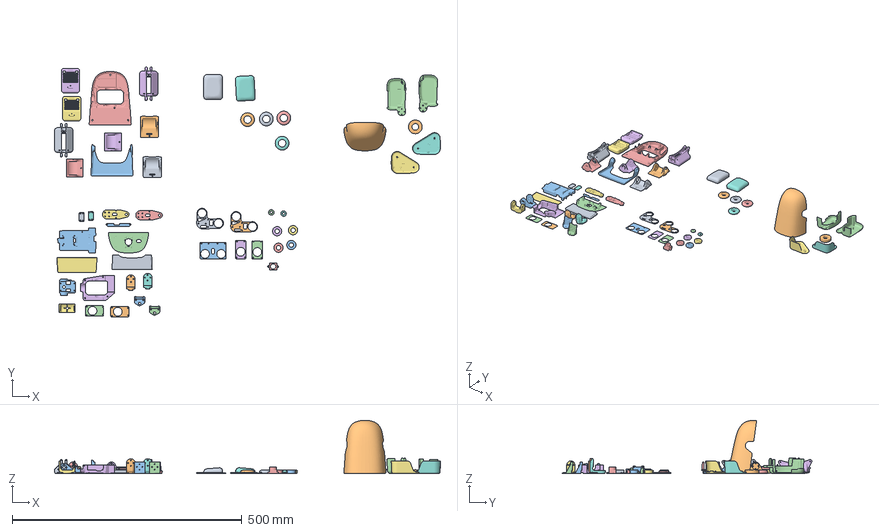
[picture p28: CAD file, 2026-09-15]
打印/microduck-飞特版-BambuStudio.3mf
840.8 x 544.5 x 116.0 mm
ankle_l_v1_脚踝左V1.stl
ankle_r_v1_脚踝右V1.stl
banana_pcb_locker_香蕉形PCB锁扣.stl
bearing_roll_轴承滚轮.stl x 2
bottom_head_shell_头部下壳.stl
foot_left_左脚.stl
foot_right_右脚.stl
hip_l_髋部左.stl x 2
jaw_soft_软下巴.stl
jaw_下巴.stl
left_shell_左壳.stl
m12_lens_holder_M12镜头座.stl
motor_support_电机支架.stl
neck_pitch_颈部俯仰.stl
neck_颈部.stl x 2
noenoeil_眼睛.stl
power_support_电源支架.stl
right_shell_右壳.stl
rim_轮辋.stl x 4
roller_blade_滚轮叶片.stl x 2
soft_mouth_top_软嘴顶部.stl
sole_left_左脚底.stl
sole_right_右脚底.stl
top_head_shell_头部上壳.stl
trunk_base_躯干底座.stl
face_part_面部零件.stp
tire_轮胎.stl x 4
轴承12×6×3.STEP x 2
ankle_right脚踝右.STEP
ankle_left_脚踝左.STEP
right_upper_leg_右上腿-FT.STEP
left_upper_leg_左上腿-FT.STEP
01-upper_leg_rigidity_plate_上腿加固板-FT.STEP x 2
99-yaw_roll_motion_偏航横滚运动-F.STEP
bearing_roll_轴承滚轮-FT.STEP x 2
leg_腿部-FT.STEP x 2

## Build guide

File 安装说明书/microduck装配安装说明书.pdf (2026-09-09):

# microduck 机器鸭

# 装配安装说明书

组件数量：15 个 | | | 依据 SolidWorks 装配图整理

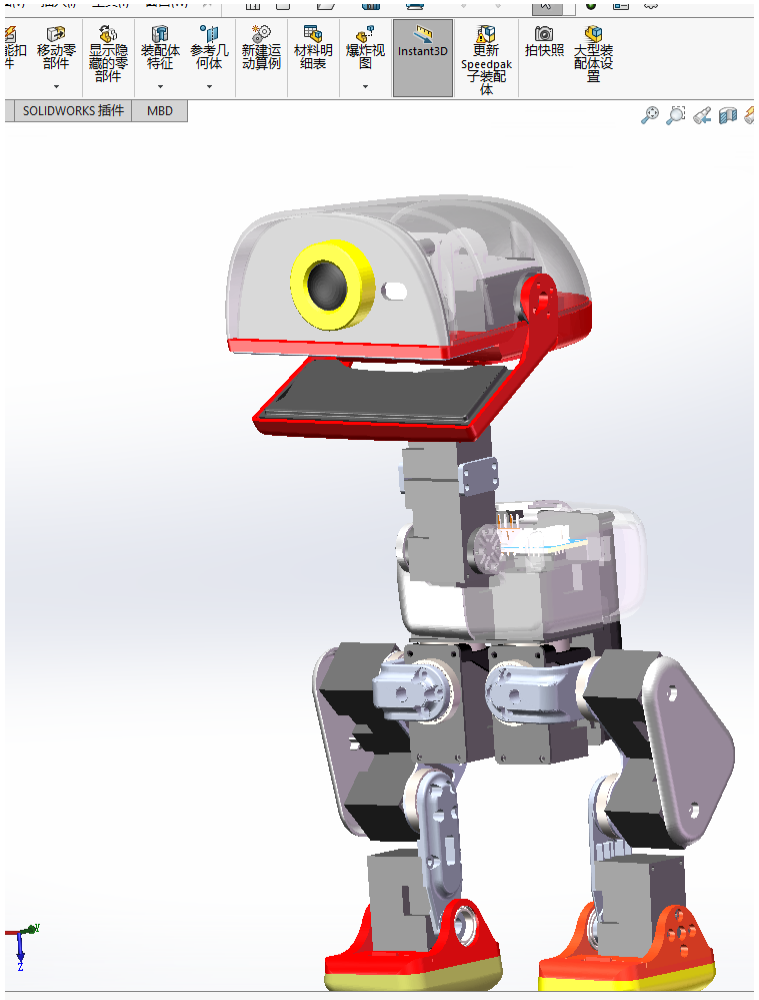
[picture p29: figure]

图 0-1 总装图（microduck 装配体）

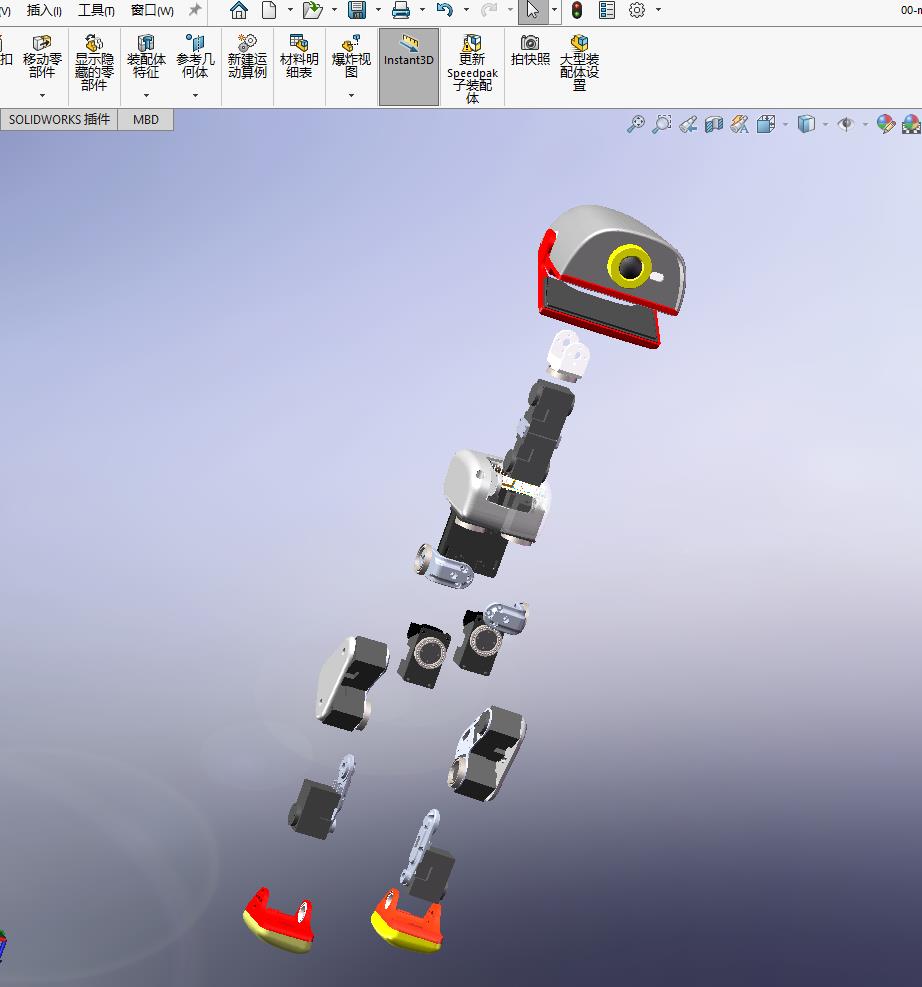
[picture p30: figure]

图 0-2 总装爆炸图

## 一、组件清单

序号 | 组件名称 | 英文 | 位置 / 功能
01 | 躯干主体 | Torso | 机身主体，全部组件的装配基准件，承 载左/右腿、颈部与控制器。
02 | 左髋 | Left Hip | 左腿根部髋关节（Pitch），实现腿部前 后摆动。
03 | 左髋 Roll | Left Hip Roll | 左腿髋部横滚（Roll）旋转关节，实现腿 部侧向摆动。
04 | 左大腿 | Left Thigh | 连接髋关节与小腿的腿节。
05 | 左小腿 | Left Calf | 连接大腿与踝关节的腿节。
06 | 左踝脚 | Left Ankle & Foot | 踝关节及脚部，实现足部转动与支撑。
07 | 颈根 | Neck Base | 颈部与机身连接处的旋转底座 （Yaw）。
08 | 颈俯仰 | Neck Pitch | 颈部俯仰（Pitch）摆动关节。
09 | 头 Yaw / Roll | Head Yaw / Roll | 头部水平摆动（Yaw）与横滚（Roll）关 节。
10 | 头部总成 | Head Assembly | 头部完整组件，含外壳、传感器/摄像头 等。
11 | 右髋 | Right Hip | 右腿根部髋关节（Pitch），与左髋镜像 对称。
12 | 右髋 Roll | Right Hip Roll | 右腿髋部横滚（Roll）旋转关节，与左髋 Roll 镜像对称。
13 | 右大腿 | Right Thigh | 连接右髋与右小腿的腿节，与左大腿镜 像对称。
14 | 右小腿 | Right Calf | 连接右大腿与右踝关节的腿节，与左小 腿镜像对称。
15 | 右踝脚 | Right Ankle & Foot | 右踝关节及脚部，与左踝脚镜像对称。

## 二、装配顺序

按组件编号（01→15）依次装配，即推荐的整机装配顺序：

1. 01 躯干主体 —— 作为整机基准先行固定；
2. 02–06 左腿 —— 依次装配 左髋 → 左髋 Roll → 左大腿 → 左小腿 → 左踝脚；
3. 07–10 颈部与头部 —— 依次装配 颈根 → 颈俯仰 → 头 Yaw/Roll → 头部总成；
4. 11–15 右腿 —— 依次装配 右髋 → 右髋 Roll → 右大腿 → 右小腿 → 右踝脚。

## 三、分组件安装说明

以下每节给出组件名称、说明、安装步骤与注意事项，配图为 SolidWorks 装配截图。

### 01 躯干主体（Torso）

【说明】机身主体，全部组件的装配基准件，承载左/右腿、颈部与控制器。


图 01-1 躯干主体

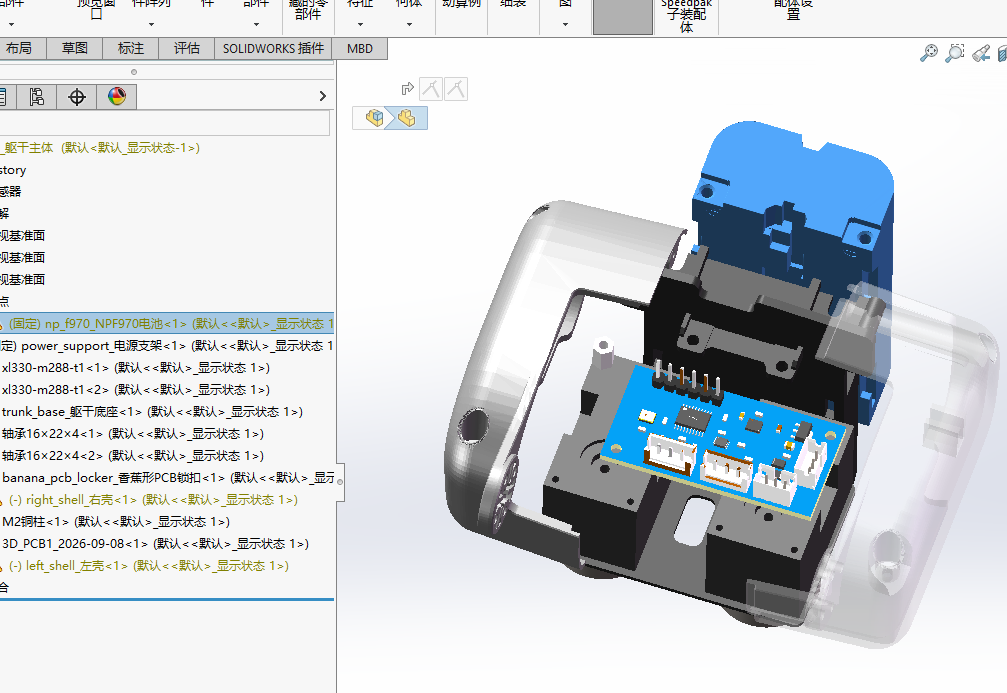
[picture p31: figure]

图 01-2 躯干主体（爆炸图）

安装步骤：
1. 1. 将躯干主体平放于工作台，检查各安装孔位、线缆出线孔与舵机安装位。
2. 2. 确认机身无毛刺、无异物，孔位螺纹完好。
3. 3. 作为装配基准固定，后续左腿、右腿、颈部均安装于本件之上。

注意事项：
- ⚠ 本件为基准件，装配过程避免强力敲击导致变形。
- ⚠ 线缆统一从机身预留孔引出，严禁压线、夹线。
- ⚠ 先确认孔位朝向，再开始安装其他组件，避免整体返工。

### 02 左髋（Left Hip）

【说明】左腿根部髋关节（Pitch），实现腿部前后摆动。

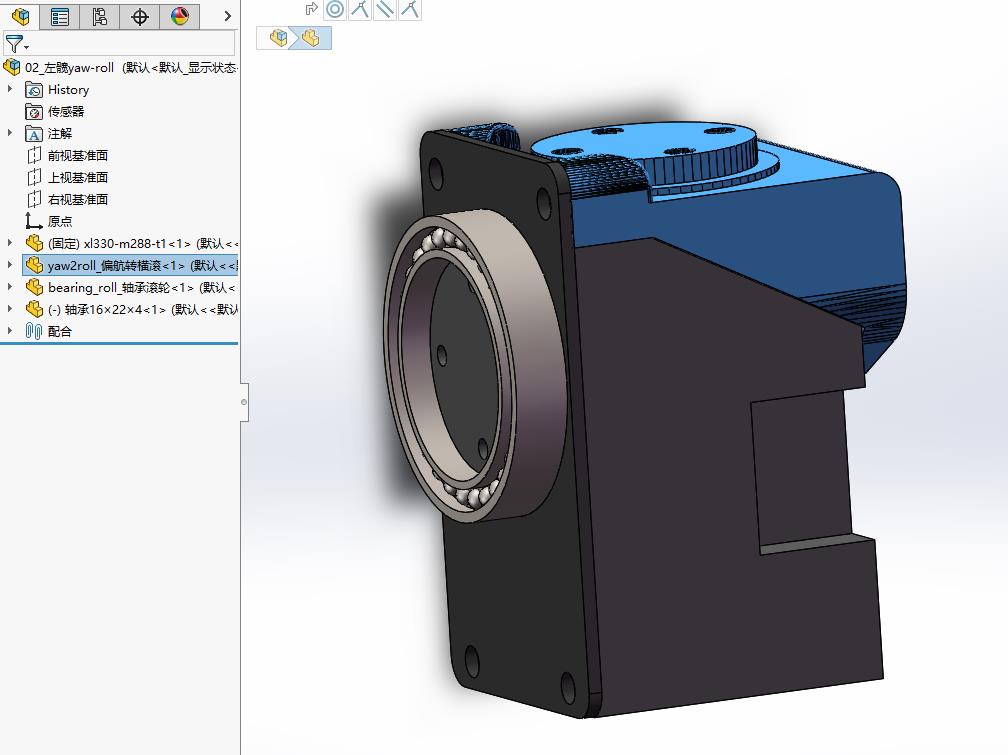
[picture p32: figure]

图 02-1 左髋

安装步骤：
4. 1. 确认左髋方向，与右髋为镜像件，注意左右区分。
5. 2. 将髋关节舵机装入安装槽，确认输出轴与转动轴线重合。
6. 3. 螺丝先对角预紧，再均匀锁紧。

注意事项：
- ⚠ 舵机装配前先通电归中位，避免偏装导致行程不对称。
- ⚠ 左右件为镜像，切勿装反。
- ⚠ 锁紧后检查关节转动是否顺畅、无卡滞。

### 03 左髋 Roll（Left Hip Roll）

【说明】左腿髋部横滚（Roll）旋转关节，实现腿部侧向摆动。

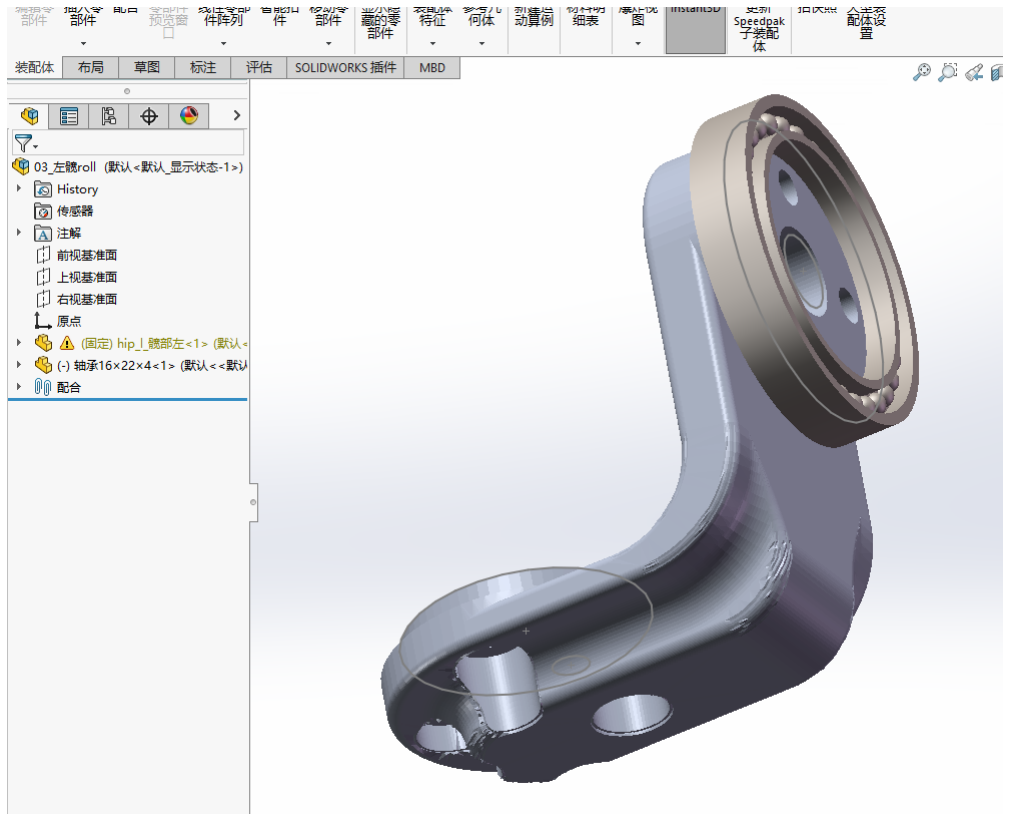
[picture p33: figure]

图 03-1 左髋 Roll

安装步骤：
7. 1. 与髋关节同轴/相邻安装，确认 Roll 轴方向。
8. 2. 固定后转动测试横滚角度范围。

注意事项：
- ⚠ 检查横滚极限位置是否与机身干涉。
- ⚠ 转动处保留适当间隙，避免摩擦发热、卡滞。

### 04 左大腿（Left Thigh）

【说明】连接髋关节与小腿的腿节。

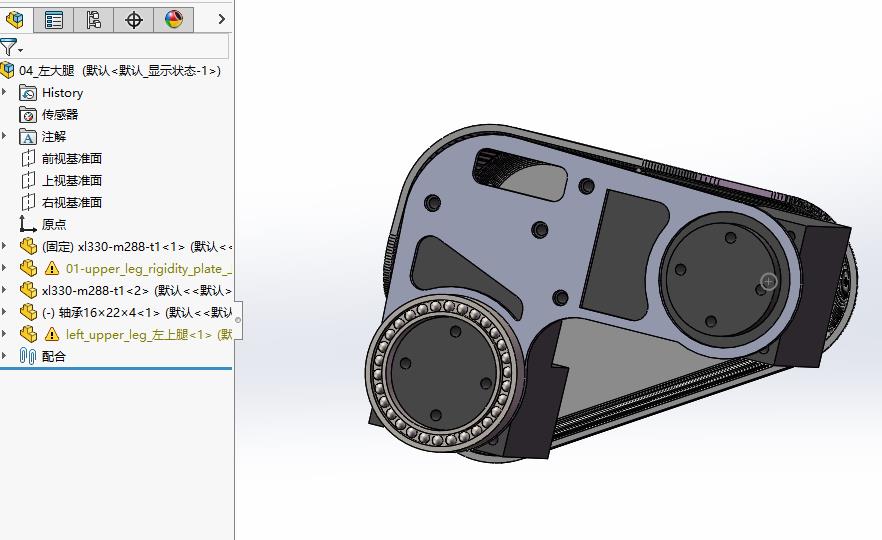
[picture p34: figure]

图 04-1 左大腿

安装步骤：
9. 1. 上端连接髋关节输出端，下端连接小腿。
10. 2. 确认上下两端轴孔对齐后锁紧。

注意事项：
- ⚠ 注意大腿与小腿的相对方向，避免反向装配。
- ⚠ 走线沿腿节外侧固定，预留关节活动余量。

### 05 左小腿（Left Calf）

【说明】连接大腿与踝关节的腿节。

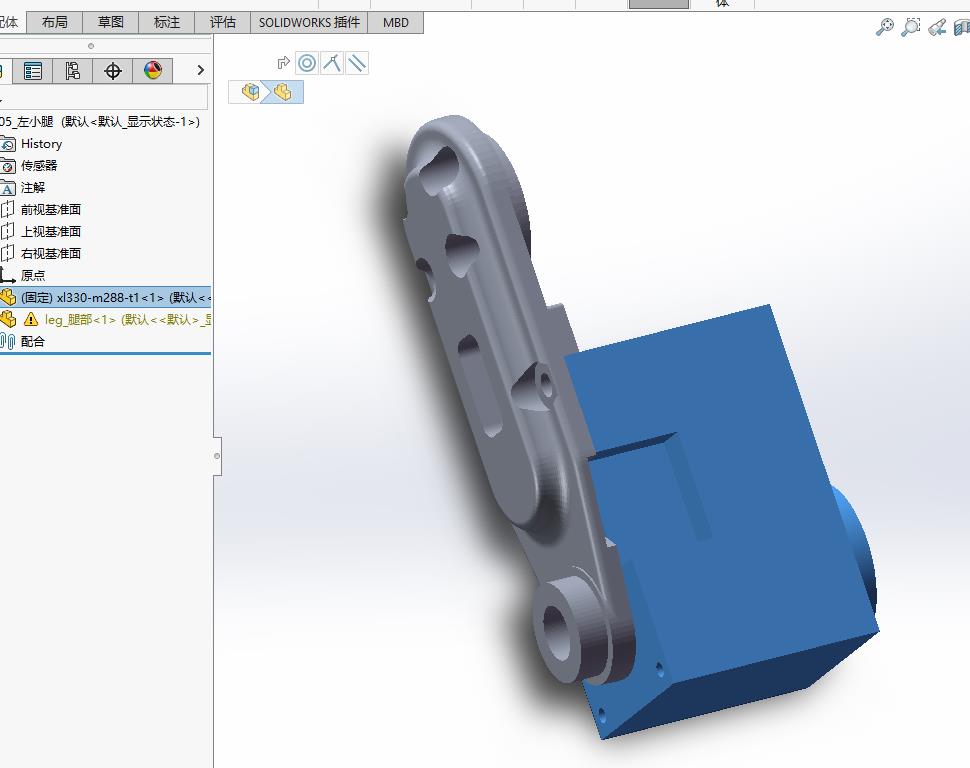
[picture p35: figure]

图 05-1 左小腿

安装步骤：

11. 1. 上端连接大腿，下端连接踝关节。
12. 2. 确认转动方向与行程后锁紧连接螺丝。

注意事项：
- ⚠ 与大腿连接处检查转动范围，防止极限位卡死。
- ⚠ 螺丝锁紧力度适中，避免塑料件开裂。

### 06 左踝脚（Left Ankle & Foot）

【说明】踝关节及脚部，实现足部转动与支撑。

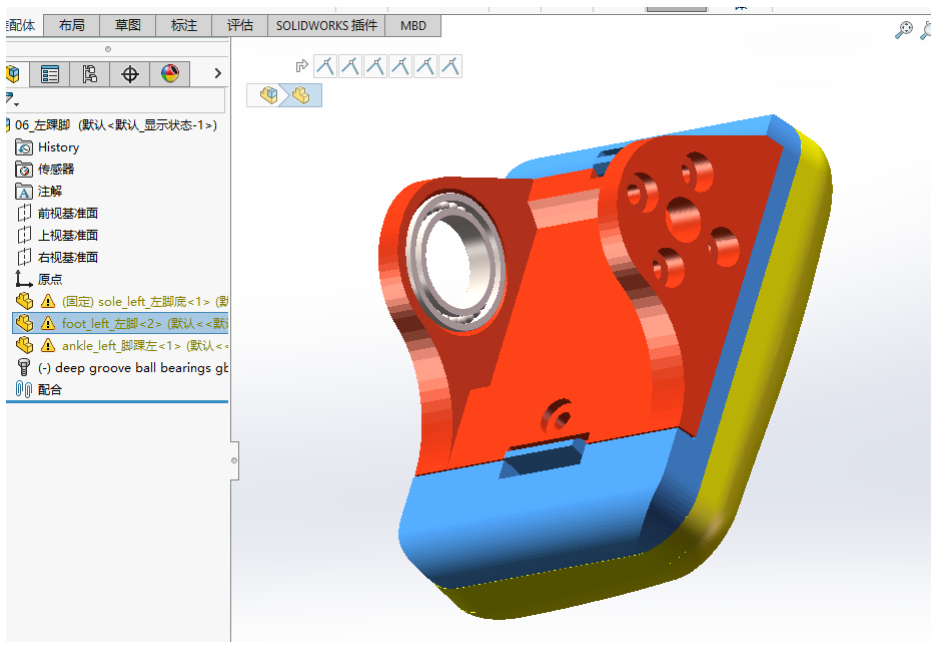
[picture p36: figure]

图 06-1 左踝脚

安装步骤：
13. 1. 上端连接小腿下端，脚部作为末端支撑件。
14. 2. 确认踝关节中位后锁紧。

注意事项：
- ⚠ 检查脚底着地平面，确保左右脚对称、站立平稳。
- ⚠ 踝关节中位标定，保证站立平衡。

### 07 颈根（Neck Base）

【说明】颈部与机身连接处的旋转底座（Yaw）。


图 07-1 颈根

安装步骤：
15. 1. 固定于机身顶部安装位，确认垂直度。
16. 2. 将颈部线缆从预留孔引出后锁紧。

注意事项：
- ⚠ 确保与机身垂直，避免后续颈部偏斜。
- ⚠ 颈部线缆预留足够长度，避免抬头/低头时拉扯。

### 08 颈俯仰（Neck Pitch）

【说明】颈部俯仰（Pitch）摆动关节。


图 08-1 颈俯仰

安装步骤：
17. 1. 上端连接头部关节，下端连接颈根。
18. 2. 确认俯仰轴方向后锁紧。

注意事项：
- ⚠ 俯仰角度范围检查，避免与躯干/头部干涉。
- ⚠ 俯仰中位标定，保证头部初始姿态正确。

### 09 头 Yaw / Roll（Head Yaw / Roll）

【说明】头部水平摆动（Yaw）与横滚（Roll）关节。

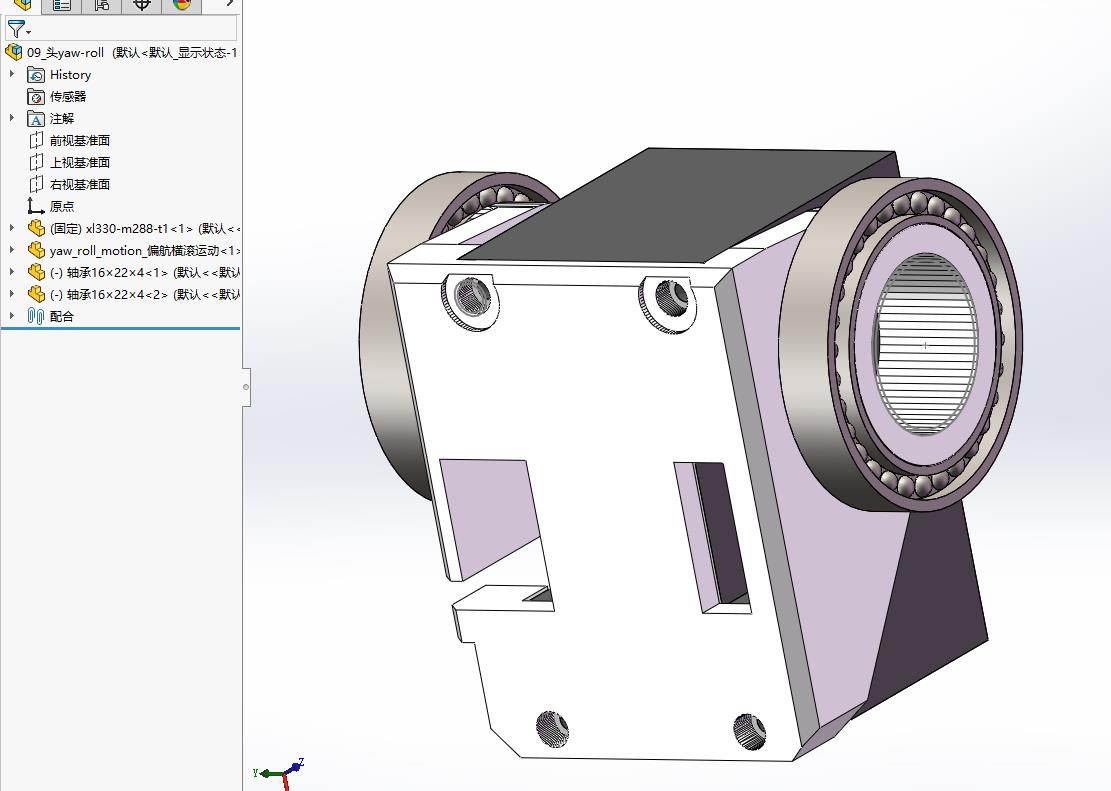
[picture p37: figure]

图 09-1 头 Yaw / Roll

安装步骤：
19. 1. 连接颈部俯仰关节与头部总成。
20. 2. 确认 Yaw/Roll 两轴方向正确后锁紧。

注意事项：
- ⚠ 头部转动范围检查，防止线缆缠绕。
- ⚠ 活动处预留线缆余量，避免扭转损伤。

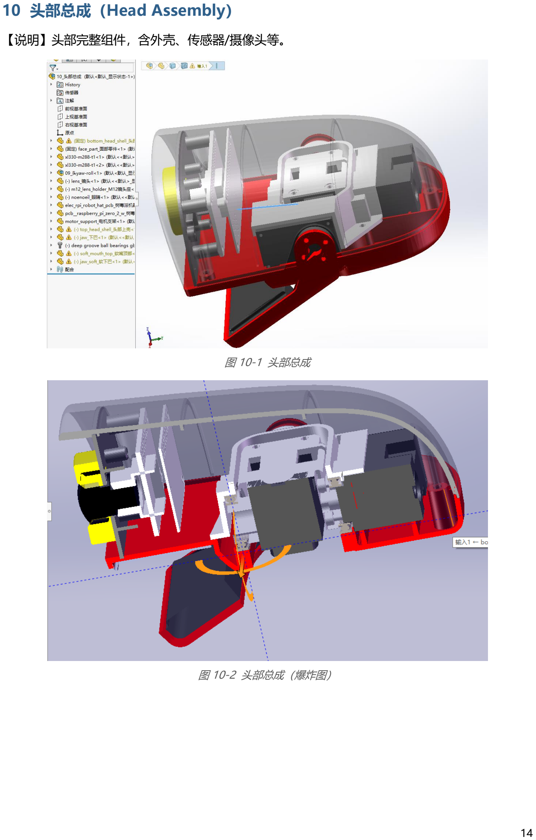
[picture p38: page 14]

### 10 头部总成（Head Assembly）

【说明】头部完整组件，含外壳、传感器/摄像头等。

图 10-1 头部总成

图 10-2 头部总成（爆炸图）


图 10-2 头部总成（爆炸图）

安装步骤：
21. 1. 按爆炸图依次装配头部内部结构（见附图）。
22. 2. 外壳与内部支架对位，安装排线与传感器。
23. 3. 闭合外壳并锁紧固定螺丝。

注意事项：
- ⚠ 外壳卡扣/螺丝对位，避免压坏排线。
- ⚠ 传感器/摄像头窗口朝向前方，确认方向。
- ⚠ 排线预留活动余量，防止头部转动时被拉扯。

### 11 右髋（Right Hip）

【说明】右腿根部髋关节（Pitch），与左髋镜像对称。

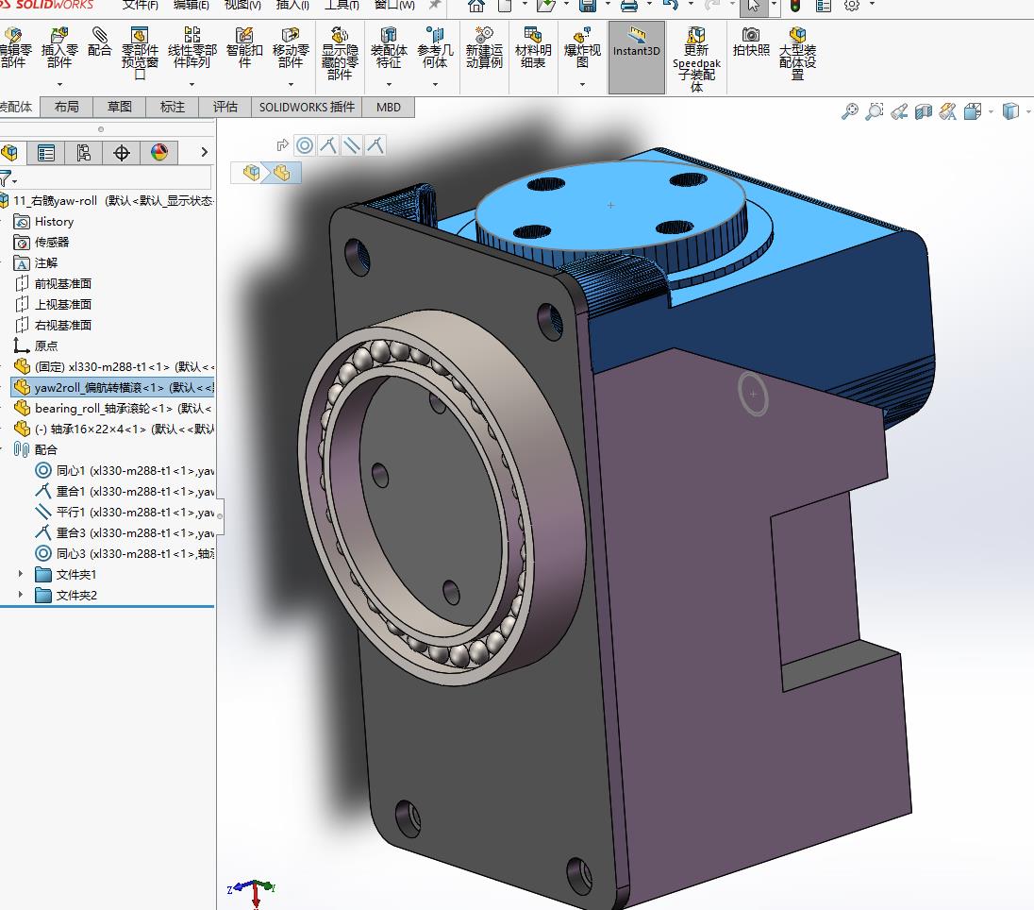
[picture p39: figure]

图 11-1 右髋

安装步骤：
24. 1. 确认右髋方向，与左髋为镜像件。
25. 2. 装入髋关节舵机，输出轴与转动轴对齐。
26. 3. 对角预紧后均匀锁紧。

注意事项：
- ⚠ 舵机先归中位再锁紧。
- ⚠ 与左髋成镜像安装，切勿装反。
- ⚠ 锁紧后检查转动顺畅。

### 12 右髋 Roll（Right Hip Roll）

【说明】右腿髋部横滚（Roll）旋转关节，与左髋 Roll 镜像对称。

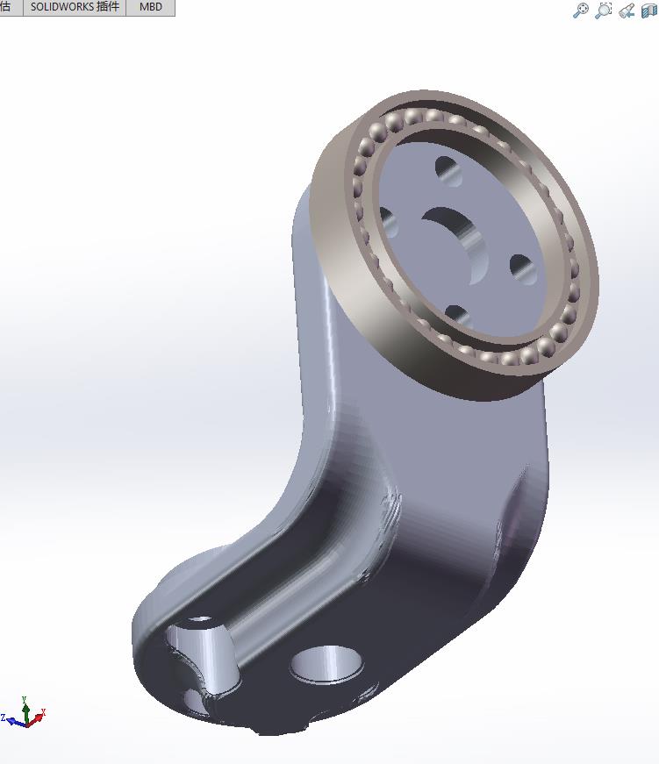
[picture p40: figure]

图 12-1 右髋 Roll

安装步骤：

27. 1. 与右髋同轴/相邻安装，确认 Roll 轴方向。
28. 2. 固定后转动测试横滚角度范围。

注意事项：
- ⚠ 检查横滚极限位置是否与机身干涉。
- ⚠ 与左髋 Roll 保持对称，保证动作一致。

### 13 右大腿（Right Thigh）

【说明】连接右髋与右小腿的腿节，与左大腿镜像对称。

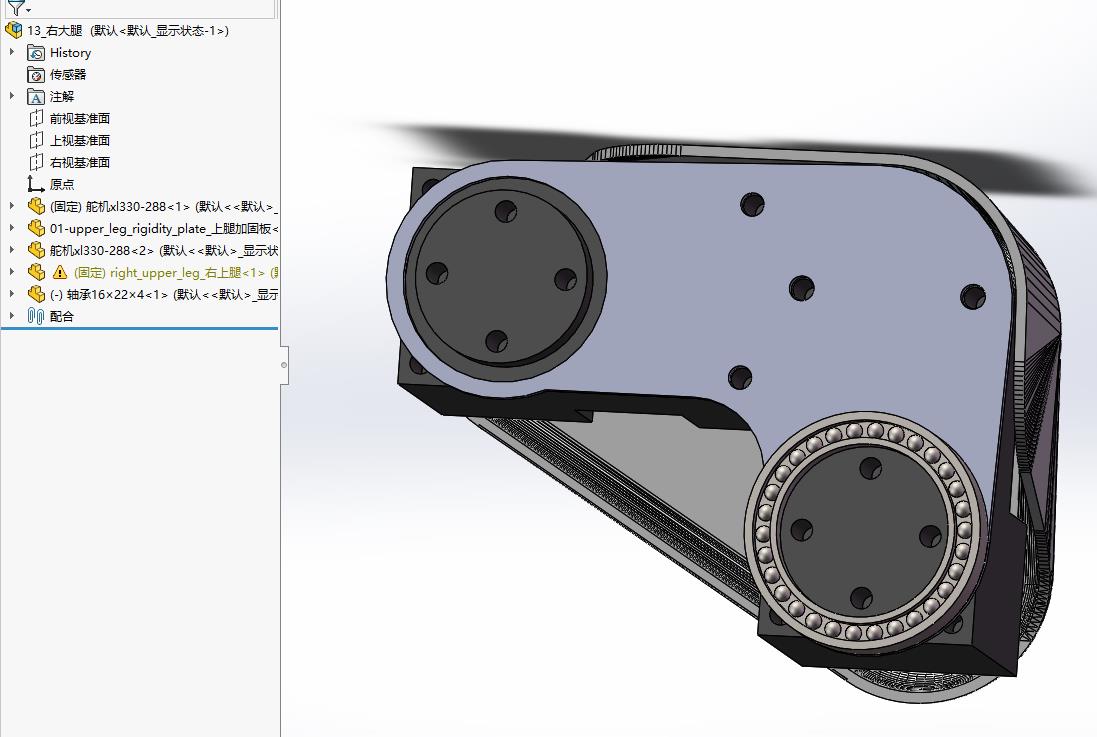
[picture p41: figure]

图 13-1 右大腿

安装步骤：
29. 1. 上端连接右髋关节输出端，下端连接右小腿。
30. 2. 确认上下轴孔对齐后锁紧。

注意事项：
- ⚠ 注意与左大腿镜像，避免反向装配。
- ⚠ 走线沿腿节外侧固定。

### 14 右小腿（Right Calf）

【说明】连接右大腿与右踝关节的腿节，与左小腿镜像对称。

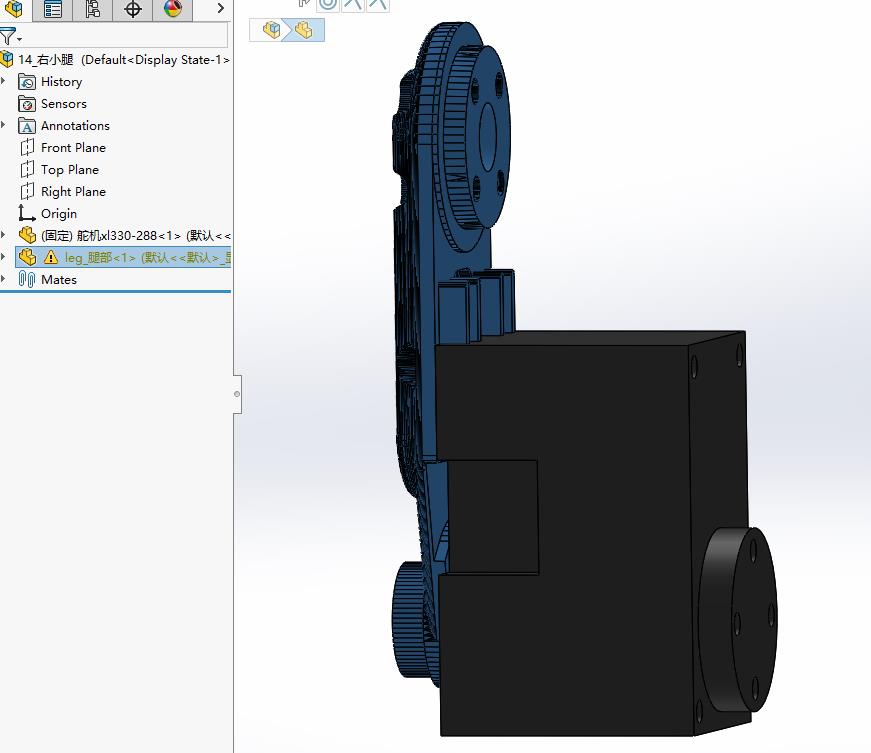
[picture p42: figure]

图 14-1 右小腿

安装步骤：
31. 1. 上端连接右大腿，下端连接右踝关节。
32. 2. 确认转动方向后锁紧。

注意事项：
- ⚠ 与左小腿镜像对称。
- ⚠ 螺丝锁紧力度适中。

### 15 右踝脚（Right Ankle & Foot）

【说明】右踝关节及脚部，与左踝脚镜像对称。

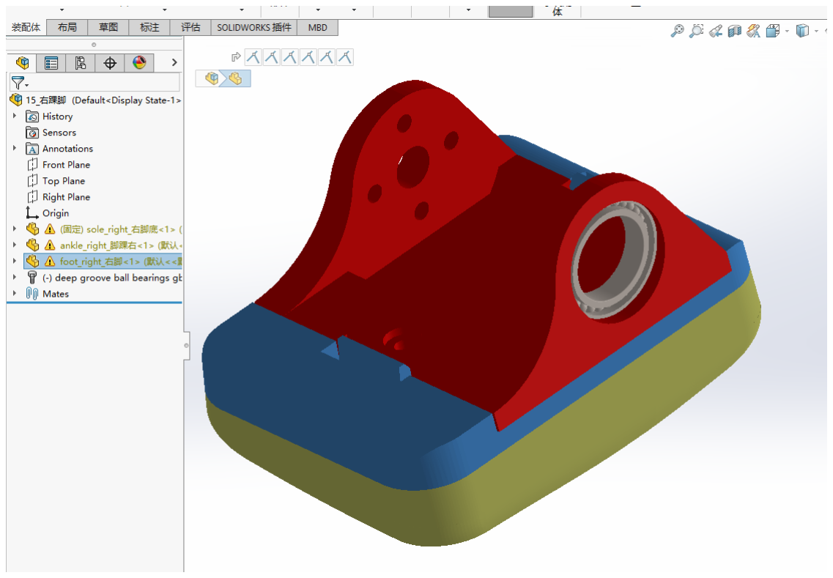
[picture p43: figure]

图 15-1 右踝脚

安装步骤：
33. 1. 上端连接右小腿下端，脚部作为末端支撑。
34. 2. 确认踝关节中位后锁紧。

注意事项：
- ⚠ 与左踝脚对称，保证双脚着地平稳。
- ⚠ 踝关节中位标定，保证站立平衡。

## 四、通用注意事项

- 装配前对照 BOM 清单清点零件数量与规格，确认 M2 和 M2.5 螺丝/紧固件型号齐全。
- 舵机类关节件：装配前先通电归中位，再锁紧，避免行程偏移。
- 螺丝采用对角分步预紧，避免单边受力导致零件变形；塑料件切勿过度锁紧。
- 左右对称件（髋 / 大腿 / 小腿 / 踝脚）务必区分左右，切勿装反。
- 线缆统一固定、预留关节活动余量，严禁压线、夹线、缠绕。
- 每完成一个活动关节，转动测试一次，检查是否干涉、卡滞、异响。
- 需要防松的连接处，建议使用适量螺纹胶（按 BOM 要求）。
- 首次通电前检查所有电气连接、绝缘与极性，确认无误后再上电。

## 五、推荐工具

- 十字 / 内六角螺丝刀（规格以 BOM 清单为准）；
- 镊子（用于细小螺丝、排线与卡扣）；
- 螺纹胶（用于需要防松的紧固件）；
- 舵机中位调试工具 / 控制板（用于关节归中位标定）。

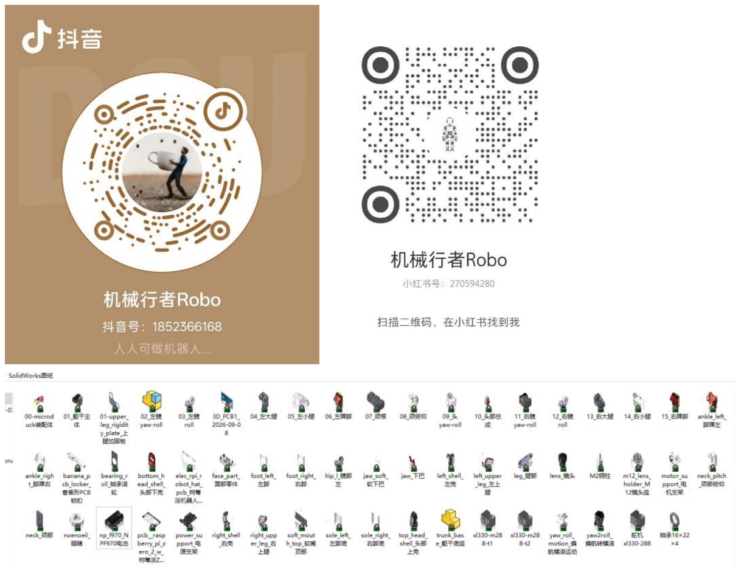
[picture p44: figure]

后续会制作安装视频，请大家关注，有问题请留言！

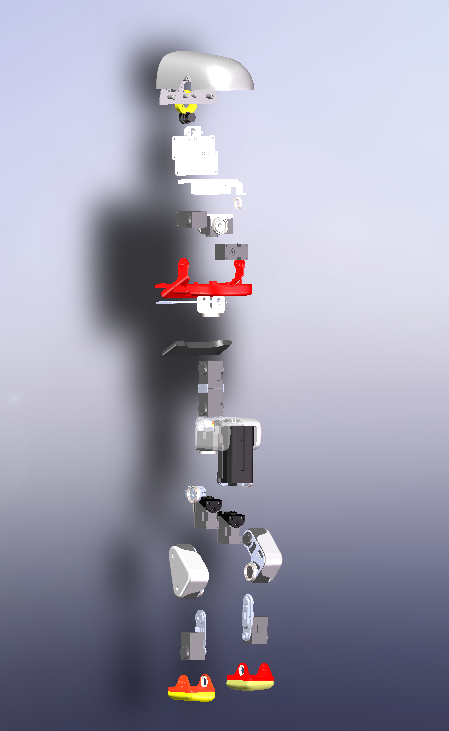
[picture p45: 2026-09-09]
组件图/00-microduck装配体爆炸图1.png

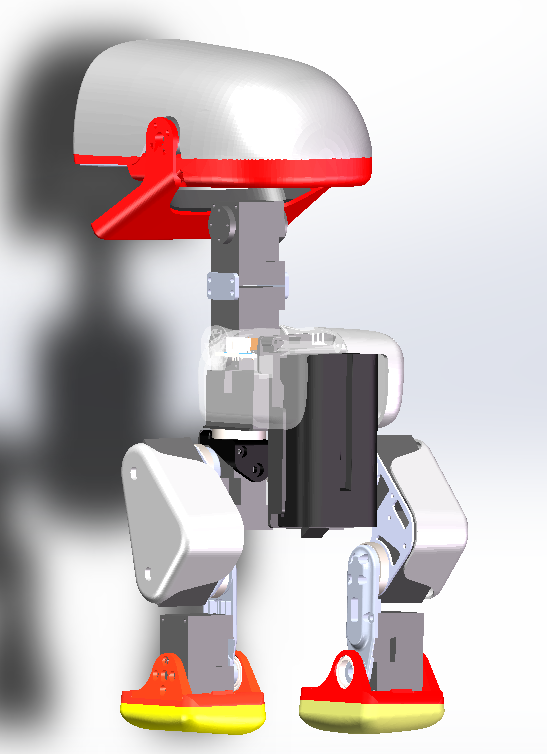
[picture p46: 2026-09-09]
组件图/00-microduck装配体2.png

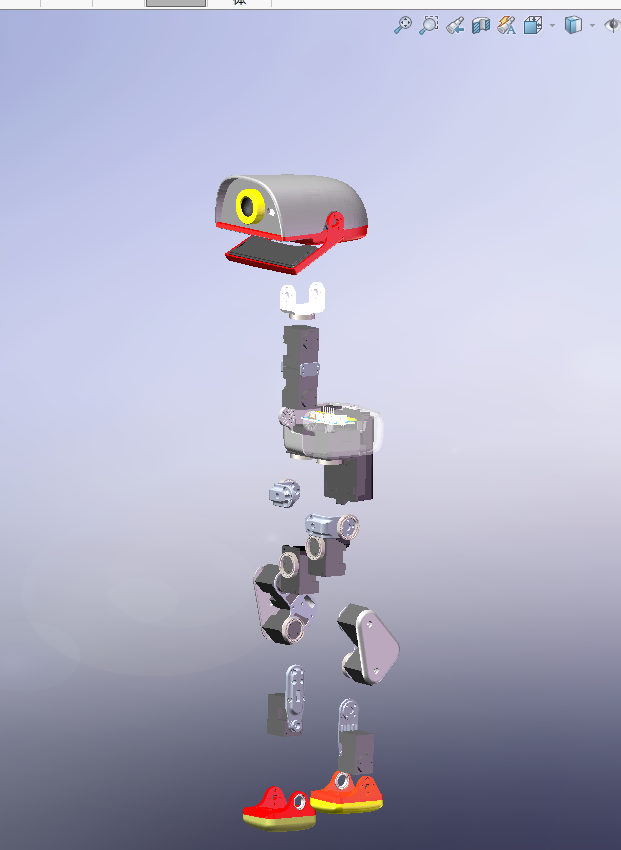
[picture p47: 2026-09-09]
组件图/00-microduck装配体爆炸图2.png

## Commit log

2026-09-09 Microduck 复刻的 SolidWorks 三维图纸与 21 页装配安装说明书
    图纸作者：机械行者Robo（小红书 270594280 / 抖音 1852366168）。
    整机从上游公开的 STL 网格重建为可编辑的参数模型，并逐个组件写了装配说明。
    本次入库的内容
    安装说明书/ 21 页 PDF，15 个组件逐个给出安装步骤、配图与注意事项，
    另有组件清单、装配顺序、通用注意事项与推荐工具
    组件图/ 23 张 SolidWorks 截图（各组件 + 总装 + 爆炸图 + 零件总览）
    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
2026-09-09 修正 Release 附件名：GitHub 会清掉文件名里的中文
    上传的是 SolidWorks图纸.zip，GitHub 存成了 SolidWorks.zip —— 附件名会被
    清理成 ASCII。README 的下载入口改成 releases/latest/download 直链，
    点一下就开始下，不用先进 Releases 页找。
    Claude-Session: https://claude.ai/code/session_01XRq4VgdHVvMJ5CzKeSpTXf
2026-09-13 v2.0 飞特 HD-1910 版图纸：舵盘凸凹不同，8 个配合件改了，已装出实物
    原版用 XL330，主仓走飞特 HD-1910。两款舵机外形接近，但 HD-1910 的舵盘
    是凸出来的、XL330 是凹进去的，跟舵盘配合的件直接装不进去。同事把这些件
    全改了、重新打印，2026-09-13 整机装出来了。
    改动件：left/right_upper_leg、leg、trunk_base、yaw2roll、bearing_roll、
    01-upper_leg_rigidity_plate、99-yaw_roll_motion（两个变体）。
    源文件走 Release v2.0：SolidWorks-FT.zip（全套 374 MB）和
    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
2026-09-13 README 顶部标明压缩包在 Releases 页；加拓竹 MakerWorld 链接
    有人在文件列表里找压缩包找不到。顶部加一行醒目提示指向右边栏的 Releases，
    再加一条拓竹 MakerWorld 的一键打印链接（机械行者Robo 上传的飞特版），
    不想下源文件的直接去那儿。
    Claude-Session: https://claude.ai/code/session_016jyYezK1kAWnAfLkveTbcL
2026-09-13 加 Bambu Studio 打印工程（5 盘排好的 3mf）和盘预览
    机械行者Robo 排好盘的 .3mf 直接进仓库 —— 4.9 MB，放 git 树里正合适，
    不用再去 Releases 找。跟拓竹 MakerWorld 上传的是同一份。
    打印/microduck-飞特版-BambuStudio.3mf P2S / 0.4 喷嘴 / PLA / 0.2 层高 / 5 盘 52 件
    打印/盘1..5.png 每盘的预览，从 3mf 里抠的
    README 下载表加一行，新增「打印」一节：参数表、五盘缩略图、怎么用
    （非拓竹打印机也能导入重切）。
    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
    [microduck-飞特版-BambuStudio.3mf]
2026-09-15 XL330 原版 v1.1、飞特版 3mf 更新到 09-15、装配 BOM 入库
    机械行者Robo 2026-09-15 发来三样：
    XL330 原版 v1.1 改了踝 / 小腿 / 脚那 8 个件（跟飞特版同一区域同步），
    加了轴承模型。57 个 SolidWorks，走 Release v1.1。
    飞特版 3mf 09-15 5 盘 52 件，对象跟 09-13 一致，内容更新，直接覆盖。
    装配 BOM xlsx 35 个打印件 + 16 个外购件，带材料和数量。原表照收进 BOM/，
    README 里按主仓查证过的事实改了四处并逐条注明：
    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
    [microduck-飞特版-BambuStudio.3mf, 装配BOM-机械行者Robo-2026-09-15.xlsx]
2026-09-15 README 顶部加「两个版本，选一个下」对照表
    v1.1 XL330 原版和 v2.0 飞特版并排：舵机、文件数、差别、打印入口、实物、下载直链。
    Claude-Session: https://claude.ai/code/session_014siuvmhv1BxiW9ucTSTGHD
2026-09-16 装配 BOM 换成 09-16 带采购链接版；README 外购件表加轴承、螺丝链接
    - BOM/装配BOM-机械行者Robo-2026-09-16-带采购链接.xlsx 替换 09-15 版
    - README 装配 BOM 一节：轴承 10×15×3 / 16×22×4 / 6×12×3、螺丝 M2×5 / M2×6 / M2.5×6
    加机械行者Robo 实际下单的淘宝 / 天猫链接，补螺纹胶一行
    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
    [装配BOM-机械行者Robo-2026-09-15.xlsx, 装配BOM-机械行者Robo-2026-09-16-带采购链接.xlsx]
2026-09-16 装配 BOM 电子件校正：舵机 15、imu_to_dxl 1、舵机线 17、电池 NP-F550；README 勘误表相应收缩
    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
    [装配BOM-机械行者Robo-2026-09-16-带采购链接.xlsx]
2026-09-18 飞特版下载链接钉死到 v2.0：releases/latest 已指向 v1.1，飞特包 404
    v1.1（XL330 版）晚于 v2.0 发布，成了 latest；README 里三处
    releases/latest/download/…-FT.zip 因此跳到 v1.1 下找文件，结果 404。
    改成 releases/download/v2.0/…，两个文件都已验证能下载。
    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
2026-10-25 docs: organize print resources and refresh assembly BOM
2026-11-03 更新 BOM 和飞特版打印工程至 2026-11-02 版
2026-11-03 BOM：修正外购件序号与合计，删除 10-23 旧版
2026-11-03 BOM：修正 NP-F550 电池单价为 47 元
